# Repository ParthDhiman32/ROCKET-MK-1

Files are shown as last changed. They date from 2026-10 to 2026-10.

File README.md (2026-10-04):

# ROCKET-MK-1
This is a fixed fin experimental rocket built for the purpose of collecting useful flight data and also showcasing high level engineering skills 

# Project Theory
For this project I will be designing simulating and fabricating a fixed fin rocket from scratch using the rocket motor as the starting point for calculating all other parameteres like the diameter of the main body tube and the nosecone length and gemoetry and the fin geometry 
the rocket motor's impulse also dictates the maximum weight of the rocket as the thrust to weight ratio should be a minimum of 5:1 considering the resistive forces acting uptom the rocket like the drag from the rocket's weight and also the aerodynamic drag which is the factor which we need to optimize our rocket for we need a very aeroynamically optimized body for the rocket to be able to cut through the air smoothly with minimum drag and deviation 
the rocket should launch perfectly vertical and shall not deviate more then 1-5 degrees from the horizontal from the launch rail The rockst's fins should be optimized to suffer from no Aerosynamic fin flutter.
Aerodynamic Fin Flutter is a destructive process in which the rocket's wings bend under stress and strain as they are travelling at very high speed (upwards of Mach 0.5) for this rocket the fins start to resonate because of the external force which the air provides for stabilizing the rocket but in this special case the air starts to resonate the fin and the fin starts to vibrate from it's mean position which and hench resonate which exposes the fin to much more flutter than it can possibly handel and hence breaks apart.
to avoid this we must use a lightweight material with the highest young's modulus which provided maximum stiffness and negligible strain 
Materials such as Fiberglass, carbon fiber, 3D printed CF-Nylong provide high stiffness ideal for optimizing the fins from restraining from fin flutter 

# Starting parameteres 
Now let's start talking about numbers and actual starting parameteres for the rocket

**Rocket Motor**
Now there are many different classes of rockets ranging from class micro and A going through E F G H I J K L and reaching to upwards of AJ
However for model rocketry we generally use from class D to the largest one S 
These rocket motor classes are alphabetical and classified by Magnitude of impulse they can produce

For my Rocket i will be using a F class rocket motor producing a Max Impulse of 67Ns
I will be using the rocketeers F57 motor 

This motor has 
Diameter of 29mm <br>
Weight = 177g (wet mass)<br>
Burn time = 1.14s<br>

This motor's casing is made from aerospace grade Aluminium 
Nozzel is manufactured out of graphite 
and all very high quality materials are used in this entire rocket motor assembly

# Rocket dimensions
Thr rocket's exact dimenstions are yet to be simulated and found out but for now we have these as the starting points
Rocket length = 650 ~ 975mm<br>
Main Body tube length = 455 ~ 650mm<br>
Avaionics bay length = 120 ~ 165mm<br>
Nose cone length 195 ~ 325mm<br>
Nose cone profile = Ogive (3:1)<br>
Outter tube diameter = 65mm<br>
Target liftoff mass = 500~600 grams<br>
Static stability margin = 1~1.5 cal<br>
3-4 Fixed fins - Trapezoid shape <br>

# Mission Objective 
Apogee > 100 Meteres<br>
Mantain Stable vertical flight <br>
All Flight Data logged successfully <br>
Working Telementry<br>
Rocket Recovery <br>

# Work Flow
Firstly the rough design will be simulated in Open rocket and the simulation data will be used for finding the perfect rocket profile values 

Then the entire rocket will be imported inside fusion 360 and the launch mechanism the launch rail and the cross section of the rocket and the fin joint mechanism and then avaionics bay will also be shown in the horizontal cross section of the rocket 

Then i will prototype the avaionics bay on breadboards and design the rough data logging program and logic This will be a time consuming process 

After this i will convert the entire avaionics circitry into a PCB which will be as small as possible and Be mounted vertically inside the Avaionics bay 

then i will also create the remote ignition and most importantly the ground telementry station which will comminucate via LoRa

After that I will work on creating proper joining mechanisms for the rocket and the final circuitry 

Then i will finalize the rocket design and start ordering parts for it's fabrication and assembly 

Then carefully assemble each and every part and test for any errors 

then calculate the Moment of inertia find the actual center of mass and center of pressure 

Simulate and perfect again in Openrocket 

Then create an even more accurate model in matlab simulink 

Test and analyze again

Then a dry run 

The Actual Flight 

# Avionics <br>
I will be using these main sensors for the avaionics (rough idea)<br>
ESP32 S3 Wroom-1<br>
BMI270 - 3 axis acceleration + 3 axis gyroscope <br>
ADXL377 - 3 axis high G accelerometer<br>
Barometric pressure sensor - altitude measurement<br>
DS3231 - Time stamping<br>
Sd card module - data logging <br>
loRa - Telementry <br>
2 Li-ion battries for Power<br>
umbilical cord connector = communication of Remote ignition from ground station to the rocket and the launch rail <br>

# Launch rail<br>
The launch rail will be made out of 2020 aluminium extrusion with arms which will hold the rocket in place (cool factor) and it will use a Rail button<br>

# OpenRocket model 
*1st Iteration estimates*


Apogee = 285m <br>
Max speed = Mach 0.245<br>
Max acceleration = 83.3m/s^2<br>

*2nd Iteration estimates*


Apogee = 281m<br>
Max speed = Mach 0.240<br>
Max acceleration = 84.6m/s^2 <br>

This version has a more agressive look and also has a much higher stability caliber(2.19Cal) then the last iteration.<br>
I upgraded from a 2020 Aluminium extrusion because a 1010 aluminium extrusion was not very easily available in india.<br>

# Render in fusion360




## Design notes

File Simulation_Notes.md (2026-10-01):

# OpenRocket simulation notes 

**Initial parameteres**
## Nose cone 
shape = Ogive <br>
Length = 150mm <br>
Base diameter = 65mm<br>
Wall thickness = 2mm<br>
Material = PETG<br>

## Body Tube
Length = 600mm<br>
Outter Diameter = 65mm<br>
inner diameter = 62mm<br>
Wall thickness = 15mm<br>

## Fins
No of fins = 4<br>
Root chod = 110mm<br>
Tip chod = 45mm<br>
Height = 50mm<br>
Sweep length = 55mm<br>
Sweep angle = 47.7mm<br>
Material = Balsa<br>

# Parachute
Parachute is 100mm below from the top of the main body tube <br>
Dia of parachute is 600mm<br>
Drag coefficient of 0.800<br>

#Mass 
Nose cone = 50g<br>
Body tube = 122g<br>
Fin set = 7.9g<br>
Center rings = 40g<br>
Flight computer = 150g<br>
Parachute = 60g<br>
Shock cord = 45g<br>
Unspecified mass = 50g<br>
Inner tube mass = 16.4g<br>
Total liftoff mass = 702g (aprox.)<br>

# **SIMULATION OUTCOME** 

APOGEE = 293m<br>
MAX VELOCITY = 85.4m/s (Mach 0.251)<br>
MAX ACCELERATION 88.6m/s <br>
STABILITY = 1.58 Cal<br>
CG = 427mm<br>
CP = 530mm<br>
Mass with motors = 525g<br>
Mass without motors = 702g<br>

Apogee without any resistive forces taken in account is 384meteres but taking aerodynamic drag the apogee drops to 285 meterest  <br>







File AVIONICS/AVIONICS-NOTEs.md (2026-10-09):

# Avionics
For rocket MK-1 

# Objective 
To record all flight data for rocket MK-1 and store it for future simulation use 
All data such as Rotation in all three axes, acceleration in all three axes, Using a magnetometer additionall to find Direction (North Suoth East West)
then we will be using a GPS to track the lockation of the rocket and all the avaionics will communicate to the ground station via LoRa transciever<br>

**Specifications**
I will be using BMI270 as the three axis accelerometer and the 3 axis gyroscope sensor mainly the gyrospcoe part the accelerometer is seconart because i will be using a different more precise sensor for finding out the acceleration 

ADXL345 is the 3 axis high G accelerometer which can detect acceleration with a range of plus minus 200Gs for reference my rocket is going to pull max to max 12Gs of acceleration
After this i will be integrating a pressure sensor which will be used to calculate the altitude of the rocket and the also help to find the point it time when it will have reached the apogee
Then i will be using a DS3231 RTC module which will give me accurate time stamps which is needed to for proper data logging 
Then comes the sd card module whioch will be holding the SD card inside the connector firmly so it does not bulge during the launch also i will be using a Push-slot connector to ensure it cannot slop off accidnetally
Then i will be using a LoRa module to comminucate with the ground control station telementry LoRa as the name suggests stands for Long Range and it is ideal for my telementry because it will precisly send me the data though may be at lower speeds by it has a very long range which is amsolutely must for my rocket 
And how can we forget the GPS moudle We will be using the U-Block NEO GPS moule

# Telementry 
we will be recieveing all the flight data from the fl;ight live to our ground telementry via LoRa where the ground telementry station will send all the data to our laptop Via UART comminucation protocol and the laptop will be running python to display all the information in forms of graphs and Text 

We will be also having a comminucation unit at the launch pad There MAY be a umbibical connector from the rocket to the launch pad which will will help the gorund station to control the rocket via wired telementry for the begining and also help the computer in determinig if the rockt has lifted off 
because first of all if we try to determine liftoff from the accelerometer only then there might be a change of error so to imcrease the redudancy of the system we will be adding another success point 
because if we fail to determine if the rocket has lifed off from the rail or not we The program will not be able to initialize and the data loggin WILL NOT start

# Ground station assembly 
The ground station will be preferrably inisde a black suitcase 
It will consist of 5 buttons which will be for T-5 to T-0 
and a big red button for launch 
without all the 5 switched T-5 to T-0 bring switched to on position the rocket will not lift off even on pessing the red button 
T-5 through T-0 buttons also have purposes 
T-5 will let the launch station's base light go red 
T-4 will let the telementry on the laptop to begin 
T-3 will let the speakers inside the ground telementry start beeping as indication of close liftoff
T-2 will make the launch rail's arm's divert from the rocket 
T-1 will start the internal telemntry of the rocket 
T-0 will be paired with the big red button for Liftoff 

Anyways now from the cool part to the technical part
The ground station will have 2 modes of communication with the rocket 1St via the umbibilical cord connector (rocket+launchrail) 2nd Via the LoRa (only rocket)
The ground station will then have as i said flip switches
The ground station will have the rocket motor igniter connected via the umbibical cord connector 

**The ground station will also have a sound system**
okay this is a cool fun part which will make the worst case scenario appear dead seriouly cool 
let me explain, So like as in aeroplanes there is a warning syste for example "Whoop Whoop Pull Up" when the terrain is approaching and the airplane is rapidly descending 
and also like "Bank angle bank angle" when the airplane tries to turn at a greater angle that the angle of repose it posseses and iits starts to rapidly fall 

So basically if the rocket goes decellerating downwards at a much higher rate like with the parachute it will have a descend velocity of about 7.74 m/s and incase of a faliure in deployment of the parachute the rocket will go well above 40 to 50 to even 60 m/s descend velocity 
in this case the Avionics will flag this as a parachute depoyment failure which will cause alrma to goo off at the ground station!!! like "Whoop Whoop Pull Up Terrain Terrain"
Cool isn't it making a bad case become a test for another part of the rocket 

# Prototyping 
SO!! for the prototyping phase i will first of all set up sensors on a breadboard connect them to an esp32 and code them to initialization first once i've done this with each sensor i want to use then i make the mock ground station telementry 
After this is finished i will move on to the actual logic developement for the rocket 

First up,
I started by researching about the specs of different components in detail and then adding them one by one in my code 
Writing the code will not be tracked by lapse but rather hackatime so first i will be starting by searching how does the code work 

First of all i set up the DHT11 code to read the temperature of the air at a specific altitude it may not be very accurate but we shall still give it a shot so there are two main variables for this purpose first one is "t" which basically stores the temperature data reading in binary coming from the sensor and then we compute the temperature in celcius using the function dht>computeHeatIndex(); which converts the values of binary temperature signals into proper celcius units 
the final temp reading is stored inside the variable "T" 

after writing this bit of code i started to research about how to set up the U-BLOC-NEO-c GPS Module 
The code snipped for the GPS module uses the TinyGPS library it starts by adding the tinygps library and then initializing the pins for the RX and TX of the U-BLOX 6M GPS module s the module uss I2C comminucation protoco we initialize it in the void setup and define it's address after that inside the void loop we use various functions inside the TinyGPS library like gps.location.lat(); for latitude or gps.location.lng(); for the longitude gps.speed.kmph for speed of the Rocket in km/h etc etc 
we will not be using the values from this esnor to determine the speed of the rocket as this gps module has a much higher latency than the other ADXL module we're using to find the acceleration at a smaple speed of 100Hz we may use this for sensor fusion if the values from this GPS moudle turn out to be accurate but most probably this will only be used as a location determining system of the recovery part of the rocket.

Finally i wrote all the functions required to manipulate files inside a sd card module 
Then i added the code to read the values of pressure from the BMP280 
Then i finally connected each the LoRa module with the esp32 and then after wiring all of this up it looked like this 

Moments like this remind me why pcbs are much better 
no-1 this board is too big to fix inside a cylendrical tube enclosure of 65mm by 50mm
no-2 one loose wire and game over
no-3 the compoenents can be easily be brought nearer to reduce EMF noise and also increase signal accuracy

Now if we talk about the code i tried to keep it very organized and clean and yes i used AI but not to a bigger extend but mainly to debug the code i wrote and to debug it mainly.

# Debugging 
So we ave written our prototype code tro check the sensors fully
What we need to do is check if each and every sensor works or not
Firstly this is the sample code 

"
#include <Wire.h>
#include <SPI.h>
#include <LoRa.h>
#include <SD.h>
#include <DHT.h>
#include <TinyGPS++.h>
#include <Adafruit_BMP280.h>
#include <Adafruit_MPU6050.h>
#include <Adafruit_Sensor.h>

#define RXD2 16 
#define TXD2 17 
#define GPS_BAUD 9600 
#define DHTPIN 4 
#define DHTTYPE DHT11  
#define BMP280_ADDRESS 0x76 

#define SD_CS_PIN 15
#define ss 5
#define rst 14
#define dio0 2

int counter = 0;

Adafruit_BMP280 bmp;
Adafruit_MPU6050 mpu;
TinyGPSPlus gps;
HardwareSerial gpsSerial(2);
DHT dht(DHTPIN, DHTTYPE);

unsigned long lastLogTime = 0;
const unsigned long LOG_INTERVAL = 1000; 
const char* logFile = "/flight_log.csv";

void setup() {
  Serial.begin(115200);
  gpsSerial.begin(GPS_BAUD, SERIAL_8N1, RXD2, TXD2);
  dht.begin();

  LoRa.setPins(ss, rst, dio0);
  while (!LoRa.begin(433E6)) {
    Serial.println("Starting LoRa failed!");
    delay(500);
  }
  LoRa.setSyncWord(0xF3);
  Serial.println("Avionics to Ground Telemetry Connection Established");
  
  if (!bmp.begin(BMP280_ADDRESS)) {
    Serial.println("BMP280 Initialization Failed!");
  }

  if (!mpu.begin()) {
    Serial.println("Failed to find MPU6050!");
  } else {
    mpu.setAccelerometerRange(MPU6050_RANGE_16_G);
    mpu.setGyroRange(MPU6050_RANGE_2000_DEG);
    mpu.setFilterBandwidth(MPU6050_BAND_260_HZ);
  }

  if (SD.begin(SD_CS_PIN)) {
    File file = SD.open(logFile, FILE_WRITE);
    if (file) {
      file.println("PacketID,UTC,Lat,Lng,Alt_GPS,Speed,Sats,Temp_DHT,Hum,Temp_BMP,Press,Alt_BMP,AccX,AccY,AccZ,GyroX,GyroY,GyroZ");
      file.close();
    }
  } else {
    Serial.println("SD Card Initialization Failed!");
  }
}

void loop() {
  while (gpsSerial.available() > 0) {
    gps.encode(gpsSerial.read());
  }

  if (millis() - lastLogTime >= LOG_INTERVAL) {
    lastLogTime = millis();

    sensors_event_t a, g, temp;
    mpu.getEvent(&a, &g, &temp);

    float t_dht = dht.readTemperature();
    float h = dht.readHumidity();
    float t_bmp = bmp.readTemperature();
    float p_bmp = bmp.readPressure();
    float a_bmp = bmp.readAltitude(1013.25);
    double lat = gps.location.lat();
    double lng = gps.location.lng();
    double alt_gps = gps.altitude.meters();
    double speed = gps.speed.kmph();
    uint32_t sats = gps.satellites.value();
    
    float mpu_ax = a.acceleration.x;
    float mpu_ay = a.acceleration.y;
    float mpu_az = a.acceleration.z;
    float mpu_gx = g.gyro.x;
    float mpu_gy = g.gyro.y;
    float mpu_gz = g.gyro.z;

    String utcStr = "NO_FIX";
    if (gps.time.isValid()) {
      char timeBuf[10];
      snprintf(timeBuf, sizeof(timeBuf), "%02d:%02d:%02d", gps.time.hour(), gps.time.minute(), gps.time.second());
      utcStr = String(timeBuf);
    }

    String dataLine = String(counter) + ",";
    dataLine += utcStr + ",";
    dataLine += String(lat, 6) + ",";
    dataLine += String(lng, 6) + ",";
    dataLine += String(alt_gps, 1) + ",";
    dataLine += String(speed, 1) + ",";
    dataLine += String(sats) + ",";
    dataLine += String(t_dht, 1) + ",";
    dataLine += String(h, 1) + ",";
    dataLine += String(t_bmp, 2) + ",";
    dataLine += String(p_bmp, 2) + ",";
    dataLine += String(a_bmp, 2) + ",";
    dataLine += String(mpu_ax, 2) + ",";
    dataLine += String(mpu_ay, 2) + ",";
    dataLine += String(mpu_az, 2) + ",";
    dataLine += String(mpu_gx, 2) + ",";
    dataLine += String(mpu_gy, 2) + ",";
    dataLine += String(mpu_gz, 2);

    Serial.println(dataLine);

    File file = SD.open(logFile, FILE_APPEND);
    if (file) {
      file.println(dataLine);
      file.close();
    }

    LoRa.beginPacket();
    LoRa.println(dataLine);
    LoRa.endPacket();

    counter++;
  }
}
" 
This code gives us this output 
"

229,00:00:00,0.000000,0.000000,0.0,0.0,0,30.6,95.0,31.23,98840.34,208.95,0.00,-91.79,16.55,-1.30,0.00,0.00
230,00:00:00,0.000000,0.000000,0.0,0.0,0,30.4,95.0,31.23,98844.50,208.60,0.00,-91.79,16.55,-1.30,0.00,0.00
231,00:00:00,0.000000,0.000000,0.0,0.0,0,30.4,95.0,31.23,98841.25,208.87,0.00,0.00,0.00,0.00,0.00,0.00
232,00:00:00,0.000000,0.000000,0.0,0.0,0,30.6,95.0,31.23,98843.00,208.72,0.00,89.21,-8.28,0.00,0.00,0.00
233,00:00:00,0.000000,0.000000,0.0,0.0,0,30.6,95.0,31.23,98842.00,208.81,0.00,0.00,0.00,0.00,0.00,0.00
"
our first value is around 229 to 233 which is basically the dataline as a timestamping method to not timestamp the exact time but later change it by checking the exact time the code begun at 

secondly we get 00:00:00 which is The RTC sensor which should output the time in a HH:MM:SS format in UTC (co-ordinated universal time) the Clock is not yet callibrated that's why we get this outpt so first we start by fixing this clock by uploading a code which sets it's exact time 
the clock shall not drift even after it will be powered off because of it' onbard CoinCell battery 

I used the library RTCds1302 to set the rtc clock's time
after that i found out conflicting pin definitions in the RTC module and LoRa both were using pin 5 as their Chip enable pin 

The main issue was that of MPU6050 the one i was using had a address of 0x70 instead of 0x68 which triggered it to abort the initilization and then what i did was change the code in the WHO_AM_I register to start the sensor even when the code isn't exactly 0x68 

Then i set the RTC time and date and finally all the sensors for the avionics were working 

Also i added a new feature inside the code 
So basically the RTC is the main clock for the system when the GPS's clock isn't working 
so now i have two times in the code one is the RTC time and then is the GPS time i will prefer to use GPS time if it is available else i shall use RTC time for plotting graphs 

Aftert this i need to start working on the ground station

# GROUND STATION 
So for the ground station i have a very cool idea that is No-1 i need an esp32 and then the LoRa RA-02 ofc along with a small speaker that i got 

Now first of all my goal is to set up the gorund station telem,netry tyo establish that the data is being transferred smoothly between the two station and then i will be working on increasing the speed of data logging in the flight controller and the speed of telementry to it's absoulte limits. then i need the speaker to be used during the following times no-1 is when the system will be started up and initialized that is iit till speak MPu6050 init BMP280 init LoRa init etc etc and then i will make it also have some emergency warnings like if the altitude decreases very suddenly the speaker will play "Whoop Whoop pull up" warning as a i mean nice easter egg and also terrain terrain if the parachute deployment fails and all

After this sytem works i will start on making the communication between this ground station and my PC set up because i need the Cool ass python graphs and Mission Control Vibes 

After this entire ground station telementry and Avionics work i will make a seperate subsystem for remote ignition of the rocket motor i need to keep this system as an external failproof system which wil only detect the signals from the ground station like 1 and 0 to ignite the fuse for the rocket motor usinf an external 12V battery which is capable of providing Very high current to set fire to the nichrome wire

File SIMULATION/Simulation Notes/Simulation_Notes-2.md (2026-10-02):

# SIMULATION-2
**Parameteres**
Nose cone shape changed from Ogive to Haack series with shape parameter 0 Von Kármán profile<br>
Noise cone length increased from 150mm to 250mm for shifting COM higher and also improving stability caliber<br>
Nose cone wall thickness decreased froim 2mm to 1.6mm to reduce weight and hence reduce drag <br>
Nose cone profile set to Smooth paint <br>


Fin Set Root chod increased from 110mm to 120mm<br>
Fin Set Tip Chord reduced from 45mm to 20mm<br>
Fin Set height increased from 50mm to 65mm<br>
Fin Set sweep angle increased from 47.7 to 64 degrees<br>


## FLIGHT PERFORMANCE CHANGES WRT ORIGINAL PARAMETERES
Overall length increased from 750mm  to 883mm<br>
Stability margin increased from 1.58 Cal to 2.19cal <br>
Simulated apogee increased from 293m to 295m  <br>
Max velocity decreased from 85.5 to 82.1 m/s (Mach 0.242)<br>
Max acceleration decreased from 88.6 to 85.5 m/s<br>

# BEFORE 


# AFTER


The point of making these changes was to increase the stability caliber of the rocket whilist also giving it a more agressive look <br>

# MASS SENSITIVITY 
Original wet mass = 735g<br>

**Case-1**
10% lesser mass = 661.5g<br>
Apogee = 339m<br>
Max Velocity = 92.2 m/s<br>
Max acceleration = 95.7 m/s^2<br>
Stability = 2.25 Cal <br>

**Case-2**
5% lesser mass = 698g<br>
Apogee = 316m<br>
Max velocity = 86.8 m/s<br>
Max acceleration = 90.4 m/s^2<br>
Stability = 2.22 Cal <br>

**Case-3**
Nominal mass = 296m<br>
Max Velocity = 82.1 m/s<br>
Max acceleration = 85.5 m/s^2<br>
Stability = 2.2 Cal<br>

**Case-4**
5% more mass = 771g<br>
Apogee = 275m<br>
Max Velocity = 77.6 m/s<br>
Max acceleration = 81.1 m/s^2<br>
Stability = 2.18 Cal <br>

**Case-5**
10% more mass = 808g<br>
Apogee = 256m<br>
Max velocity = 73.6 m/s<br>
Max acceleration = 77.1 m/s<br>
Stability = 2.15 Cal<br>

## GRAPHED DATA





## Wind sensitivity 
**case-1**
Windspeed = 0 m/s<br>
Apogee = 297m<br>
Max velocity = 82 m/s<br>
Max acceleration = 85.5 m/s^2<br>
Stability = 2.2 Cal <br>
Velocity off rod = 15.2 m/s
Optimim delay = 6.89 seconds<br>
Time to apogee = 14s<br>
Flight time = 37.9s<br>
Ground hit velocity = 16.1 m/s<br>

**Case-2**
Windspeed = 2 m/s<br>
Apogee = 296m<br>
Max velocity = 82.1 m/s<br>
Max acceleration = 85.5 m/s^2<br>
Stability = 2.2 Cal <br>
Velocity off rod = 15.2 m/s<br>
Optimum delay =  6.88s<br>
Time to apogee = 14s<br>
Flight time = 22.7s<br>
Ground hit velocity = 64.8m/s<br>

**Case-3**
Windspeed = 4 m/s<br>
Apogee = 289m<br>
Max velocity = 81.7 m/s<br>
Max acceleration = 85.6 m/s^2<br>
Stability = 2.2 Cal<br>
Velocity off rod = 15.2 m/s<br>
Optimum delay = 6.79s <br>
Time to apogee = 13.9s<br>
Flight time = 22.1s<br>
Ground hit velocity = 64.5 m/s<br>

**Case-4**
Windspeed = 6 m/s <br>
Apogee = 282m<br>
Max velocity = 81.3 m/s<br>
Max acceleration = 85.6 m/s^2<br>
Velocity off rod = 15.2 m/s<br>
Optimum delay = 6.69 s<br>
Time to apogee = 13.8 s<br>
Flight time = 21.8 s<br>
Ground hit velocity = 63.7 m/s <br>

## OBSERVATIONS 
Apogee decreases 2.6m every 1 m/s increase in wind velocity <br>
Velocity is not affected much by wind velocity (although weathercoking may occur because of higher Stability caliber)<br>
Max acceleration is almost insensetive to wind speed<br>
Stability caliber is constant because it does not directly depend on wind velocity but rather the change in wind velocity may produce a change in the center of pressure which may affect Stability Caliber<br>
Velocity off rod is not affected by wind velocity <br>
Optional delay decreases by 2.9% for every 1 m/s increase in wind velocity <br>
Time to apogee decreases almost by 0.2s for every 1 m/s increase in wind velocity <br>

## GRAPHED DATA 





# OUTCOME 


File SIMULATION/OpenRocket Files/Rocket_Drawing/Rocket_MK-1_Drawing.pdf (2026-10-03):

## Rocket Design

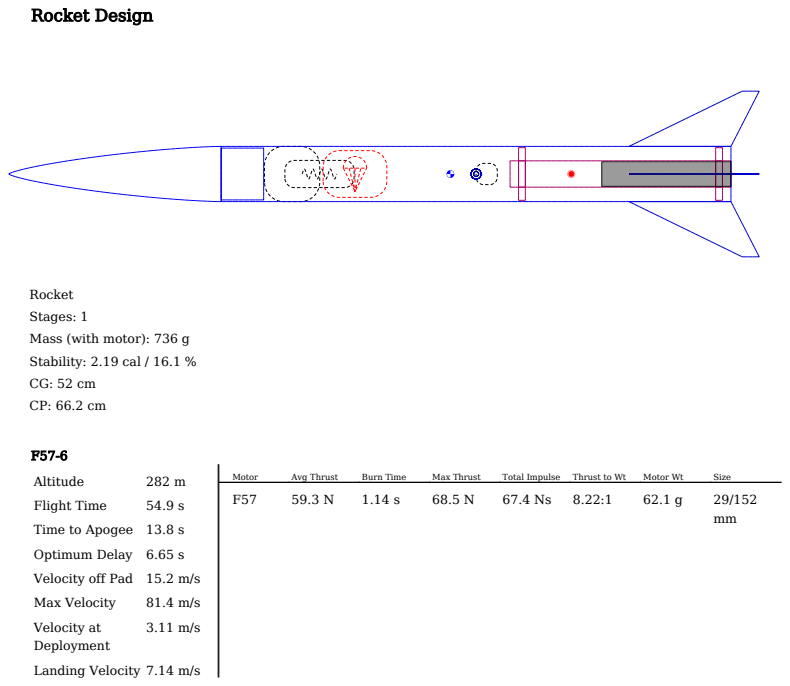
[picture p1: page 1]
Altitude; Flight Time; Optimum Delay 6.65 s; Max Velocity; Velocity at; Deployment; Landing Velocity 7.14 m/s; Motor; Avg Thrust; Burn Time; Max Thrust; Total Impulse; Thrust to Wt; Motor Wt; Size

Rocket
Stages: 1
Mass (with motor): 736 g
Stability: 2.19 cal / 16.1 %

Time to Apogee 13.8 s

Velocity off Pad 15.2 m/s

## Parts Detail

Stage: Sustainer

Pod Set: Pod Set

Nose Cone | PETG - 100%
infill

(1.25 g/cm³)

Haack series | Len: 25 cm | Mass: 64.3 g
Body Tube | Cardboard

(0.68 g/cm³)

Diain 6.2 cm
Diaout 6.5 cm
Len: 60 cm | Mass: 122 g
Trapezoidal Fin Set (4) | Balsa

(0.17 g/cm³)

Thick: 0.3 cm | Mass: 9.28 g
Inner Tube | Cardboard

(0.68 g/cm³)

Diain 2.9 cm
Diaout 3.1 cm
Len: 26 cm | Mass: 16.7 g
Centering Ring | Cardboard

(0.68 g/cm³)

Diain 3.1 cm
Diaout 6.2 cm
Len: 0.8 cm | Mass: 20 g
Centering Ring | Cardboard

(0.68 g/cm³)

Diain 3.1 cm
Diaout 6.2 cm
Len: 0.8 cm | Mass: 20 g
Flight Computer | Diaout 6.5 cm | Mass: 150 g
Parachute | Ripstop nylon

(67 g/m²)

Diaout 60 cm | Len: 7.5 cm | Mass: 60 g
Shroud Lines | Elastic cord
(round 2 mm,
1/16 in)

(1.8 g/m)

Lines: 6 | Len: 30 cm
Shock Cord | Elastic cord
(round 2 mm,
1/16 in)

(1.8 g/m)

Len: 300 cm | Mass: 45 g
Unspecified | Diaout 2.5 cm | Mass: 50 g
Rail Button | PETG - 100%
infill

(1.25 g/cm³)

Len: 0 cm | Mass: 1.5 g

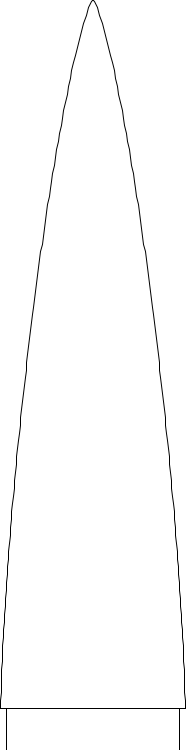
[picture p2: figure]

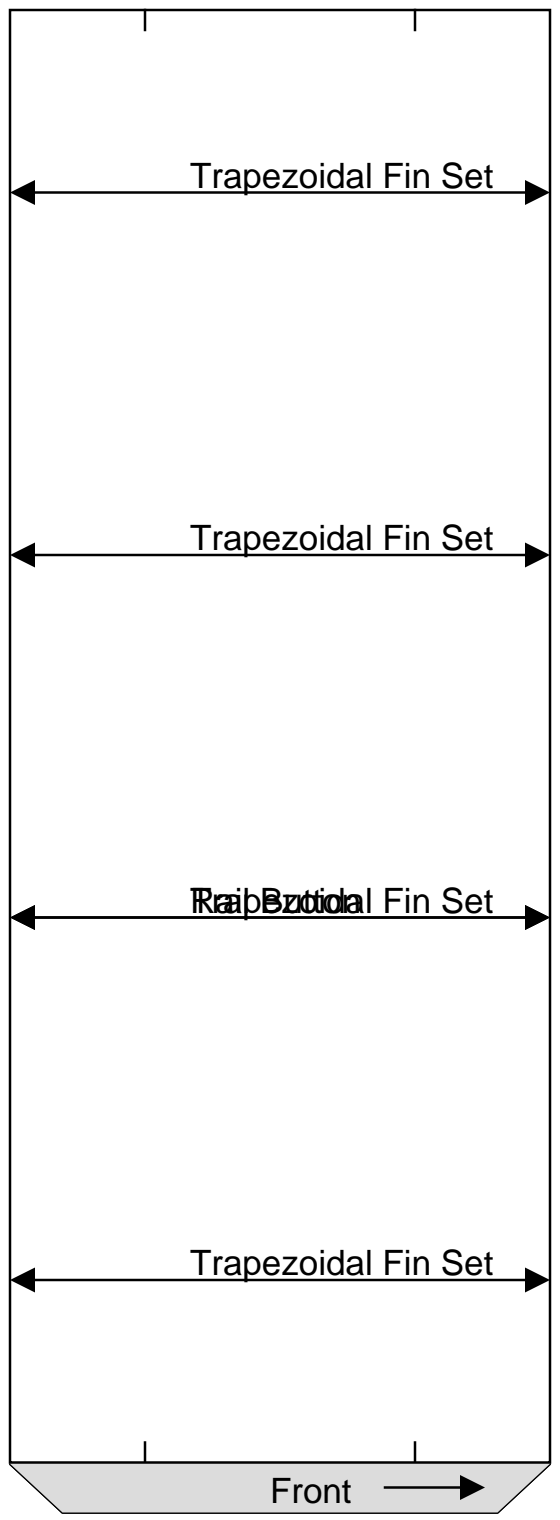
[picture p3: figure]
Front; Trapezoidal Fin Set; Rail Button

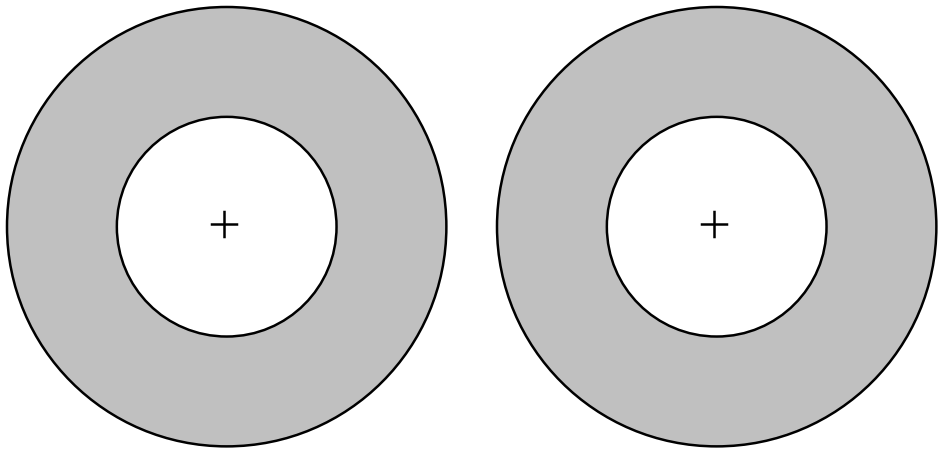
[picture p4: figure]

## in cm

cm
in

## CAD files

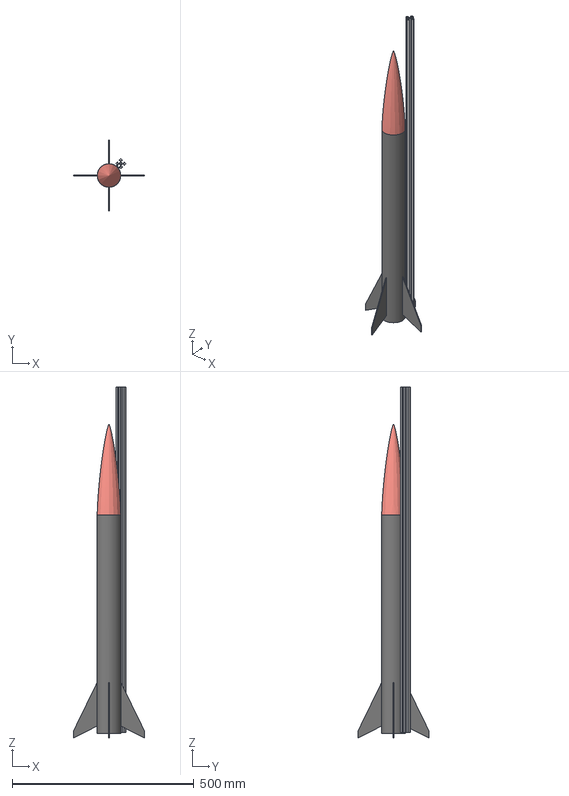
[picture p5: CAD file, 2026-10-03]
SIMULATION/CAD files/Rocket assembly file/Rocket_MK-1_Launch_Rail_Assembly v1.step
194.8 x 194.8 x 965.0 mm
Rocket motor
Main_Body_Tube
Nose Cone
Fins
BSHCS ANSI B18.3.1M - M2x0.4 x 8 Steel Grade 2 Plain
2020 alu section

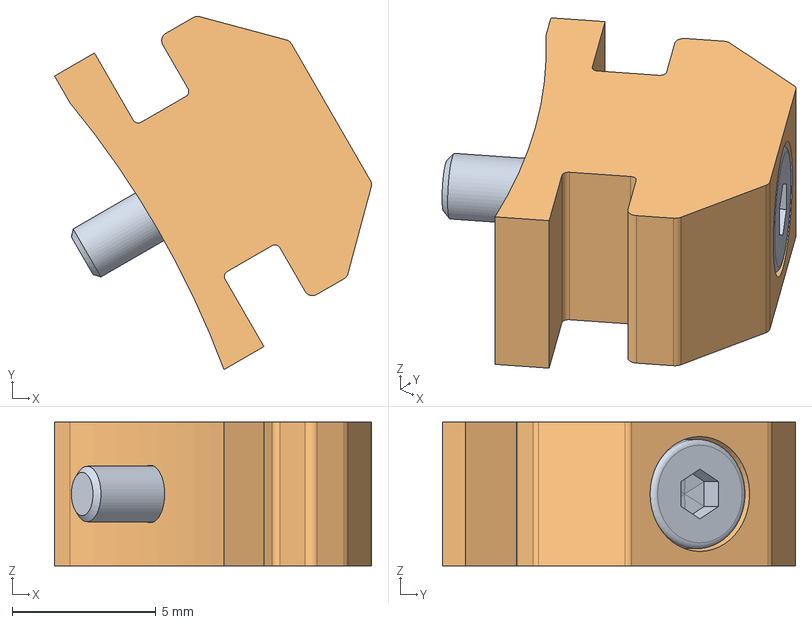
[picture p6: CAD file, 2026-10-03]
SIMULATION/CAD files/Rail Button/RailButton v6.step
11.0 x 12.3 x 5.00 mm

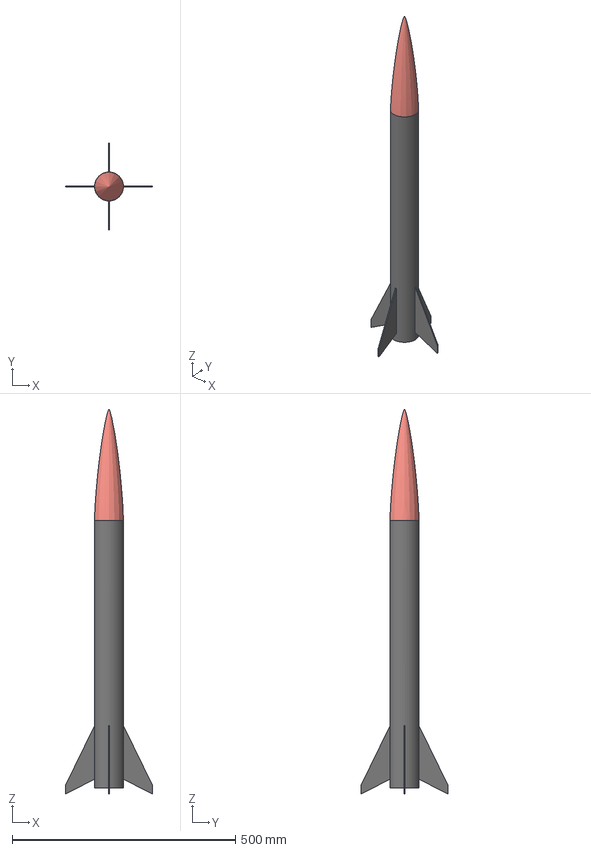
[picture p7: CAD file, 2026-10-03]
SIMULATION/CAD files/Rocket MK-1/Rocket_MK-1.step
194.8 x 194.8 x 863.0 mm
Rocket motor
Main_Body_Tube
Nose Cone
Fins

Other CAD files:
SIMULATION/CAD files/Rocket assembly file/Rocket_MK-1_Launch_Rail_Assembly v2.iges
SIMULATION/CAD files/Rail Button/RailButton v6.iges
SIMULATION/CAD files/Rocket MK-1/Rocket_MK-1.f3d

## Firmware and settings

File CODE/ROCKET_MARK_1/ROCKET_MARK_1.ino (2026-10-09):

#include <Wire.h>
#include <SPI.h>
#include <LoRa.h>
#include <SD.h>
#include <DHT.h>
#include <TinyGPS++.h>
#include <Adafruit_BMP280.h>
#include <Adafruit_MPU6050.h>
#include <Adafruit_Sensor.h>
#include <ThreeWire.h>
#include <RtcDS1302.h>

#define I2C_SDA 21
#define I2C_SCL 22

#define RXD2 16 
#define TXD2 17 
#define GPS_BAUD 9600 

#define DHTPIN 4 
#define DHTTYPE DHT11  

#define SD_CS_PIN 15
#define LORA_CS_PIN 5
#define LORA_RST_PIN 14
#define LORA_DIO0_PIN 2

#define DS1302_DAT  25
#define DS1302_SCLK 26
#define DS1302_RST  27

// TARGET LOG INTERVAL: 20ms = 50 Hz Data Logging & Telemetry Loop
const unsigned long LOG_INTERVAL = 20; 
const char* logFile = "/flight_log.csv";

ThreeWire myWire(DS1302_DAT, DS1302_SCLK, DS1302_RST);
RtcDS1302<ThreeWire> Rtc(myWire);

Adafruit_BMP280 bmp;
Adafruit_MPU6050 mpu;
TinyGPSPlus gps;
HardwareSerial gpsSerial(2);
DHT dht(DHTPIN, DHTTYPE);

File flightLog;

int counter = 0;
unsigned long lastLogTime = 0;
unsigned long lastRtcRead = 0;
unsigned long lastDhtRead = 0;

bool bmpReady = false;
bool mpuReady = false;
bool sdReady = false;
bool loraReady = false;
bool dhtReady = false;
bool gpsHardwareReady = false;

// Shared sensor data buffers
char rtcTimeBuf[10] = "00:00:00";
char gpsTimeBuf[10] = "00:00:00";
float t_dht = 0.0, h_dht = 0.0;

void setup() {
  Serial.begin(115200);

  pinMode(DS1302_RST, OUTPUT);
  digitalWrite(DS1302_RST, LOW);

  pinMode(SD_CS_PIN, OUTPUT);
  digitalWrite(SD_CS_PIN, HIGH);
  pinMode(LORA_CS_PIN, OUTPUT);
  digitalWrite(LORA_CS_PIN, HIGH);

  delay(1000); 
  Serial.println("\n=== ROCKET MK-1 HIGH-SPEED BOOT SEQUENCE ===");

  // 1. Upgrade I2C to Fast Mode (400 kHz)
  Wire.begin(I2C_SDA, I2C_SCL);
  Wire.setClock(400000);
  delay(100);

  Serial.print("Initializing MPU6050 IMU... ");
  if (mpu.begin(0x68) || mpu.begin(0x69)) {
    mpuReady = true;
    mpu.setAccelerometerRange(MPU6050_RANGE_16_G);
    mpu.setGyroRange(MPU6050_RANGE_2000_DEG);
    mpu.setFilterBandwidth(MPU6050_BAND_260_HZ);
    Serial.println("[SUCCESS]");
  } else {
    Serial.println("[FAILED]");
  }

  Serial.print("Initializing BMP280 Barometer... ");
  if (bmp.begin(0x76) || bmp.begin(0x77)) {
    bmpReady = true;
    Serial.println("[SUCCESS]");
  } else {
    Serial.println("[FAILED]");
  }

  Serial.print("Initializing DS1302 RTC... ");
  Rtc.Begin();
  if (Rtc.GetIsWriteProtected()) Rtc.SetIsWriteProtected(false);
  if (!Rtc.GetIsRunning()) Rtc.SetIsRunning(true);

  RtcDateTime compiled = RtcDateTime(__DATE__, __TIME__);
  RtcDateTime now = Rtc.GetDateTime();
  if (!now.IsValid() || now < compiled) {
    Rtc.SetDateTime(compiled);
    Serial.println("[SUCCESS] -> Time synced to build.");
  } else {
    Serial.println("[SUCCESS] -> Running from backup power.");
  }

  Serial.print("Initializing DHT11... ");
  dht.begin();
  delay(300); 
  float testT = dht.readTemperature();
  if (!isnan(testT)) dhtReady = true;
  Serial.println(dhtReady ? "[SUCCESS]" : "[WARNING] -> Async sampling enabled");

  Serial.print("Initializing GPS UART2... ");
  gpsSerial.begin(GPS_BAUD, SERIAL_8N1, RXD2, TXD2);
  Serial.println("[SUCCESS]");

  // 2. High-Speed LoRa Radio Configuration
  digitalWrite(SD_CS_PIN, HIGH);
  digitalWrite(LORA_CS_PIN, LOW);
  LoRa.setPins(LORA_CS_PIN, LORA_RST_PIN, LORA_DIO0_PIN);
  
  Serial.print("Initializing High-Speed LoRa Transceiver... ");
  if (LoRa.begin(433E6)) {
    loraReady = true;
    LoRa.setSyncWord(0xF3);
    LoRa.setSignalBandwidth(500E3); // 500 kHz Bandwidth for max data rate
    LoRa.setSpreadingFactor(7);     // SF7 for fast airtime
    LoRa.setCodingRate4(5);         // CR 4/5
    LoRa.setTxPower(17);
    Serial.println("[SUCCESS]");
  } else {
    Serial.println("[FAILED]");
  }
  digitalWrite(LORA_CS_PIN, HIGH);

  // 3. Persistent File Opening on SD Card
  digitalWrite(LORA_CS_PIN, HIGH);
  digitalWrite(SD_CS_PIN, LOW);
  
  Serial.print("Initializing SD Card Logging Stream... ");
  if (SD.begin(SD_CS_PIN)) {
    sdReady = true;
    flightLog = SD.open(logFile, FILE_WRITE);
    if (flightLog) {
      flightLog.println("PacketID,RTC_Time,GPS_Time,Lat,Lng,Alt_GPS,Speed,Sats,Temp_DHT,Hum,Temp_BMP,Press,Alt_BMP,AccX,AccY,AccZ,GyroX,GyroY,GyroZ");
      flightLog.flush();
    }
    Serial.println("[SUCCESS]");
  } else {
    Serial.println("[FAILED]");
  }
  digitalWrite(SD_CS_PIN, HIGH);

  Serial.println("=== BOOT SEQUENCE COMPLETE: MAX SPEED LOGGING READY ===\n");
}

void loop() {
  // Non-blocking GPS Stream Processing
  while (gpsSerial.available() > 0) {
    gps.encode(gpsSerial.read());
  }

  // Non-blocking RTC update every 1000ms (prevents slow bit-bang SPI overhead on every cycle)
  if (millis() - lastRtcRead >= 1000) {
    lastRtcRead = millis();
    RtcDateTime now = Rtc.GetDateTime();
    if (now.IsValid()) {
      snprintf(rtcTimeBuf, sizeof(rtcTimeBuf), "%02d:%02d:%02d", now.Hour(), now.Minute(), now.Second());
    }
  }

  // Non-blocking DHT11 update every 2000ms
  if (dhtReady && (millis() - lastDhtRead >= 2000)) {
    lastDhtRead = millis();
    float t = dht.readTemperature();
    float h = dht.readHumidity();
    if (!isnan(t)) t_dht = t;
    if (!isnan(h)) h_dht = h;
  }

  // Update GPS time buffer asynchronously when valid
  if (gps.time.isValid()) {
    snprintf(gpsTimeBuf, sizeof(gpsTimeBuf), "%02d:%02d:%02d", gps.time.hour(), gps.time.minute(), gps.time.second());
  }

  // High-Speed Execution Loop
  if (millis() - lastLogTime >= LOG_INTERVAL) {
    lastLogTime = millis();

    double lat = 0.0, lng = 0.0, alt_gps = 0.0, speed = 0.0;
    uint32_t sats = 0;

    if (gps.location.isValid()) lat = gps.location.lat();
    if (gps.location.isValid()) lng = gps.location.lng();
    if (gps.altitude.isValid()) alt_gps = gps.altitude.meters();
    if (gps.speed.isValid()) speed = gps.speed.kmph();
    sats = gps.satellites.value();

    float t_bmp = 0.0, p_bmp = 0.0, a_bmp = 0.0;
    if (bmpReady) {
      t_bmp = bmp.readTemperature();
      p_bmp = bmp.readPressure();
      a_bmp = bmp.readAltitude(1013.25);
    }

    float mpu_ax = 0.0, mpu_ay = 0.0, mpu_az = 0.0;
    float mpu_gx = 0.0, mpu_gy = 0.0, mpu_gz = 0.0;
    if (mpuReady) {
      sensors_event_t a, g, temp;
      mpu.getEvent(&a, &g, &temp);
      mpu_ax = a.acceleration.x;
      mpu_ay = a.acceleration.y;
      mpu_az = a.acceleration.z;
      mpu_gx = g.gyro.x;
      mpu_gy = g.gyro.y;
      mpu_gz = g.gyro.z;
    }

    // High-speed static C-string buffer (zero heap memory allocations)
    char dataBuffer[300];
    snprintf(dataBuffer, sizeof(dataBuffer),
      "%d,%s,%s,%.6f,%.6f,%.1f,%.1f,%u,%.1f,%.1f,%.2f,%.2f,%.2f,%.2f,%.2f,%.2f,%.2f,%.2f,%.2f",
      counter, rtcTimeBuf, gpsTimeBuf, lat, lng, alt_gps, speed, sats,
      t_dht, h_dht, t_bmp, p_bmp, a_bmp,
      mpu_ax, mpu_ay, mpu_az, mpu_gx, mpu_gy, mpu_gz
    );

    // 1. Output to Serial
    Serial.println(dataBuffer);

    // 2. High-Speed SD Card Logging
    if (sdReady && flightLog) {
      digitalWrite(LORA_CS_PIN, HIGH);
      digitalWrite(SD_CS_PIN, LOW);
      
      flightLog.println(dataBuffer);
      
      // Flush buffer to physical SD flash memory every 20 packets to guarantee zero data loss on crash
      if (counter % 20 == 0) {
        flightLog.flush();
      }
      digitalWrite(SD_CS_PIN, HIGH);
    }

    // 3. High-Speed Non-blocking LoRa Transmission
    if (loraReady) {
      digitalWrite(SD_CS_PIN, HIGH);
      digitalWrite(LORA_CS_PIN, LOW);
      
      LoRa.beginPacket();
      LoRa.print(dataBuffer);
      LoRa.endPacket(true); // Async/Non-blocking transmit mode
      
      digitalWrite(LORA_CS_PIN, HIGH);
    }

    counter++;
  }
}

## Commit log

2026-10-03 Updated CAD Files
    [RailButton v6.iges, RailButton v6.step, Rocket_MK-1.f3d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]
2026-10-04 Organized stuff
    [RailButton v6.iges, RailButton v6.step, Rocket_MK-1.f3d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]
2026-10-11 Ground station debugging
2026-10-12 Ground station Telementry
2026-10-17 Started working on Avionics PCB
2026-10-21 pcb dev
2026-10-24 Avionics CAD progression
2026-10-25 completed remote ignition circuit
2026-10-25 Add Theory.md for Remote Ignition System documentation
    Added documentation for the Remote Ignition System, detailing its purpose, working mechanism, and PCB design considerations.
2026-10-28 Add Theory.md for Remote Ignition System documentation
    Added a new section on casing for the PCB and included images of the progression.
